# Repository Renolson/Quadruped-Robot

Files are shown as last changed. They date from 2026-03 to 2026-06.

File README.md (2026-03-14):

<h1 align="center">🐾 12-DOF Quadrupedal Robot</h1>

<p align="center">
<b>Development of a 12-DOF Quadrupedal Robot with Enhanced Navigation</b>
</p>

<p align="center">





</p>
------------------------------------------------------------------------

# 🤖 Project Overview

This project presents the **design and development of a
12‑Degree‑of‑Freedom (12‑DOF) quadrupedal robot** capable of navigating
uneven terrain.

Traditional wheeled robots struggle on **rocky surfaces, stairs, and
irregular ground**.\
Legged robots provide superior mobility by adapting their footholds and
posture.

Our robot uses:

-   🧠 **Raspberry Pi embedded control**
-   ⚙️ **High‑torque servo actuators**
-   🦾 **12 articulated joints**
-   🖥 **Inverse kinematics based motion control**
-   🎮 **Remote controller interface**

The goal is to create a **cost‑effective quadruped research platform**
suitable for robotics experimentation and education.

------------------------------------------------------------------------

# 🐕 Robot Preview

<p align="center">
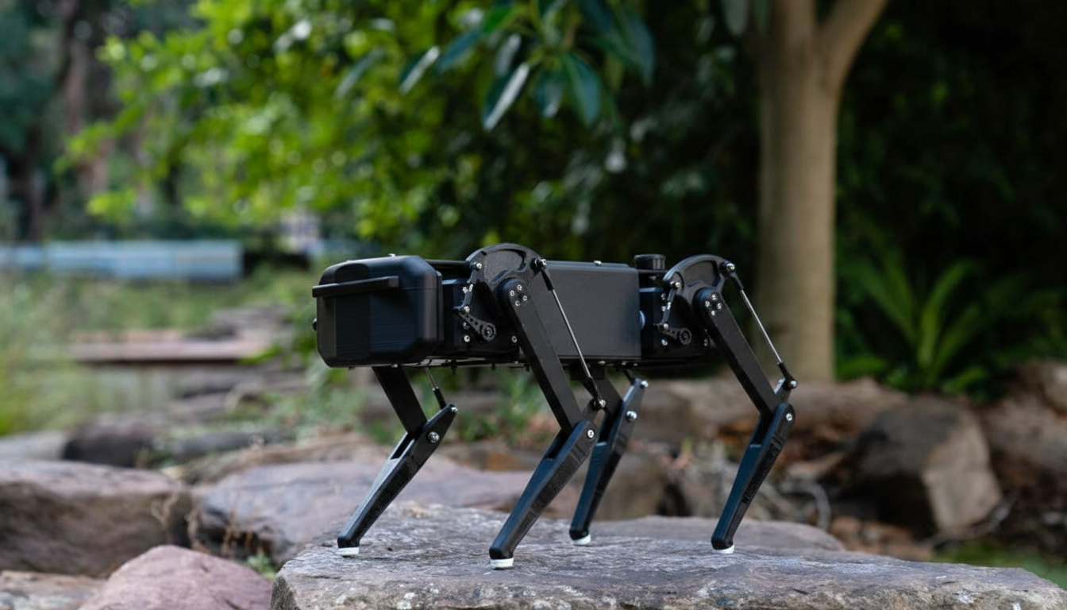
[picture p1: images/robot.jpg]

</p>

> This is a 3D design inspired and altered from the Open Source 3D model- DINGO THE ROBOT DOG.
> Credits Goes to the respective owners

------------------------------------------------------------------------

# ✨ Key Features

  Feature                         Description
  ------------------------------- -----------------------------------------
  🦾 12‑DOF Leg Design            3 joints per leg for natural locomotion
  🧠 Embedded Control             Raspberry Pi based architecture
  ⚙️ Torque‑Validated Actuation   Analytical actuator selection
  🎮 Remote Control               PS4 controller / keyboard input
  🧩 Modular Design               Easy upgrades for future research
  🌍 Terrain Adaptability         Handles uneven surfaces and slopes

------------------------------------------------------------------------

# 🧠 System Architecture

    User Input (PS4 Controller / Keyboard)
                │
                ▼
          Raspberry Pi Controller
                │
          Gait Controller
                │
          Inverse Kinematics
                │
          Hardware Interface
                │
            Servo Driver
                │
            Servo Motors

------------------------------------------------------------------------

# ⚙️ Robot Specifications

  Parameter            Value
  -------------------- ------------------
  Degrees of Freedom   12 DOF
  Leg Configuration    3 joints per leg
  Body Length          380 mm
  Body Width           250 mm
  Shoulder Height      250 mm
  Thigh Length         140 mm
  Shank Length         140 mm
  Robot Mass           \~3 kg
  Payload Capacity     \~0.5 kg

------------------------------------------------------------------------

# 🔧 Hardware Components

## Embedded Controller

-   Raspberry Pi

## Actuators

-   STS3215 Serial Servo
-   35kg PWM Servo

## Mechanical Structure

-   3D printed polycarbonate components

## Communication

-   I2C servo communication
-   PWM servo control

------------------------------------------------------------------------

# 🧮 Torque Validation

Joint torque was analytically calculated to ensure proper actuator
selection.

Example:

τ = m × g × L

For the knee joint:

τ ≈ 2.06 Nm

Selected actuators provide **higher torque than required**, ensuring
stable operation.

------------------------------------------------------------------------

# 🧪 Testing

The robot was tested through several stages:

### Static Testing

-   Posture validation
-   Load‑bearing verification
-   Joint limit testing

### Dynamic Testing

-   Forward walking
-   Turning
-   Incline traversal

### Monitoring

-   Servo temperature
-   Power consumption

The robot successfully demonstrated **stable walking and controlled
locomotion**.

------------------------------------------------------------------------

# 🌍 Applications

Quadrupedal robots can be used in:

-   🚨 Disaster inspection
-   🧭 Rough terrain exploration
-   🌾 Agricultural monitoring
-   🏭 Industrial inspection
-   🔍 Search and rescue missions

------------------------------------------------------------------------

# 🔮 Future Work

Future improvements may include:

-   Computer vision navigation
-   SLAM based localization
-   IMU stabilization
-   Autonomous path planning
-   Advanced gait optimization

------------------------------------------------------------------------

# 📂 Repository Structure

    quadruped-robot
    │
    ├── CAD
    │   ├── body_design
    │   └── leg_components
    │
    ├── firmware
    │   └── servo_control
    │
    ├── control
    │   ├── gait_controller
    │   └── inverse_kinematics
    │
    ├── simulation
    │   └── gazebo
    │
    ├── electronics
    │   └── wiring_diagrams
    │
    ├── images
    │   ├── robot.jpg
    │   └── demo.gif
    │
    └── README.md

------------------------------------------------------------------------

# 🎓 Academic Information

**BSc Engineering (Hons)**\
Department of Electrical and Telecommunication Engineering\
South Eastern University of Sri Lanka

### Authors

Balakumar Premamyuresan\
Sahayanathan Renolson\
Jeyapalasingam Jeluxshan

### Supervisors

Dr. W.G.C.W Kumara\
Dr. Ajmal Hinas\
Eng. S. Sampavi

------------------------------------------------------------------------

# ⭐ Contribution

This project demonstrates that **locally engineered quadrupedal robots** can be developed using accessible hardware, supporting robotics research and education.

---

# 📜 License

Academic research project.

---

<p align="center">
⭐ If you like this project, consider giving it a star!
</p>

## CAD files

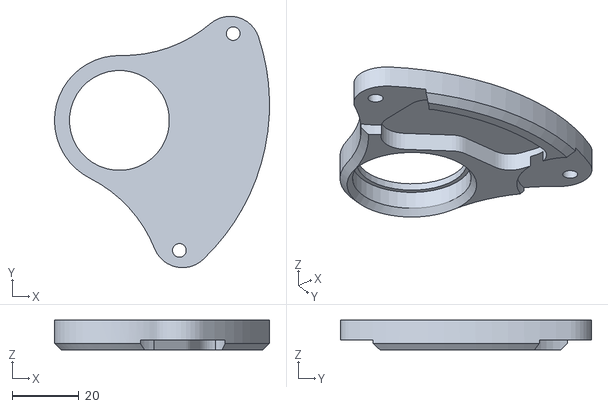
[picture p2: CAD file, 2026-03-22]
Printed parts outside/left leg front STL/leg left - Servo CAM offset modd-1.STL
64.6 x 75.5 x 9.00

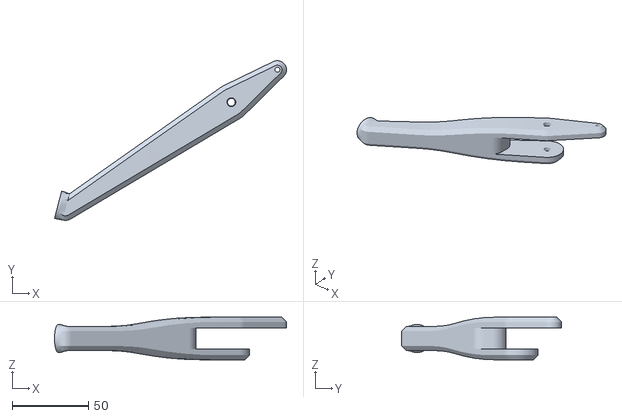
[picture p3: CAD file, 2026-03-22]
Printed parts outside/left leg front STL/leg left - RIGHT Lower Leg simpleMirror-2.STL
152.5 x 105.0 x 28.0

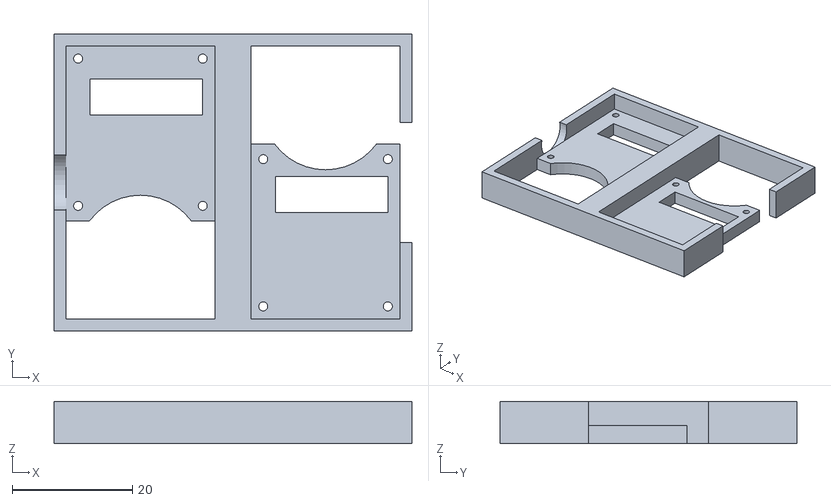
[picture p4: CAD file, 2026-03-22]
Printed parts outside/left leg front STL/12servo - cover12servo-1.STL
59.6 x 49.4 x 7.00

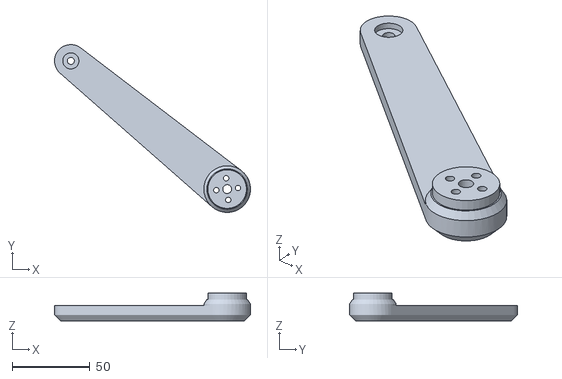
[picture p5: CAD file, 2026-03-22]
Printed parts outside/left leg front STL/leg left - RIGHT upper leggg-1.STL
126.0 x 107.9 x 18.0

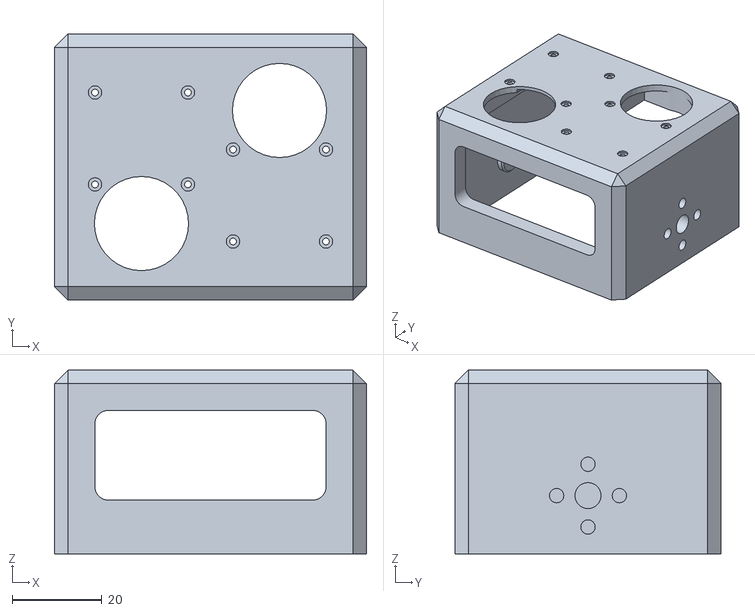
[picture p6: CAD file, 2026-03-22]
Printed parts outside/left leg front STL/12servo - holder3-1.STL
69.6 x 59.4 x 41.0

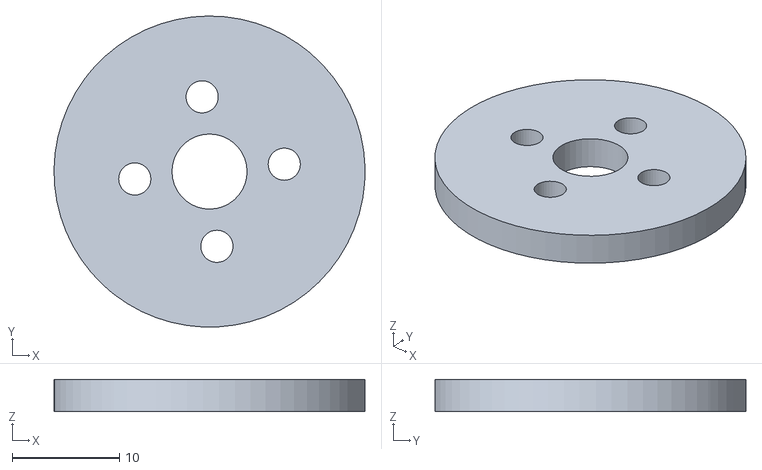
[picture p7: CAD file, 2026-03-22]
Printed parts outside/left leg front STL/leg left - Upper leg bearing washerr-1.STL
29.0 x 29.0 x 3.00

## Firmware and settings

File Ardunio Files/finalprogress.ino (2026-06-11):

#include <INST.h>
#include <SCS.h>
#include <SCSCL.h>
#include <SCSerial.h>
#include <SCServo.h>
#include <SMS_STS.h>
#include <Arduino.h>
#include <math.h>

// =====================================================
// ESP32 + FE-URT-1 + 12 x STS3215
// Complete Robot Dog Demo Code (Walking + Gestures)
// CH1: Forward / Backward Trot
// CH5: Push-up / Back push-up
// CH6 HIGH: Hip sway
// CH6 LOW: Sitting + Heart / Hi gestures
// =====================================================

// ---------------- UART SETTINGS ----------------
#define SERVO_RX 16
#define SERVO_TX 17
#define SERVO_BAUD 1000000

HardwareSerial ServoSerial(1);
SMS_STS sts;

// ---------------- RC RECEIVER ----------------
#define CH1_PIN 32
#define CH5_PIN 27
#define CH6_PIN 14

// ---------------- MOTOR SETTINGS ----------------
const int NUM_MOTORS = 12;

int motorID[NUM_MOTORS] = {
  1, 2, 3,
  4, 5, 6,
  7, 8, 9,
  10, 11, 12
};

// =====================================================
// REAL MOTOR MAPPING
// =====================================================

// Front Right
#define FR_LOWER 1
#define FR_UPPER 2
#define FR_HIP   3

// Front Left
#define FL_HIP   10
#define FL_UPPER 11
#define FL_LOWER 12

// Back Left
#define BL_HIP   4
#define BL_UPPER 6
#define BL_LOWER 5

// Back Right
#define BR_HIP   9
#define BR_UPPER 7
#define BR_LOWER 8

// =====================================================
// FIXED HOME POSITION
// =====================================================

int fixedHomePos[NUM_MOTORS] = {
  2000, 2110, 2045,
  2000, 1885, 2120,
  2048, 2075, 2100,
  2100, 2048, 2048
};

int homePos[NUM_MOTORS];
int currentCmdPos[NUM_MOTORS];

// =====================================================
// SITTING POSES
// =====================================================

// Go here first when sitting
int intermediateSitPose[NUM_MOTORS] = {
  2549, 2596, 2076,
  2019, 2513, 2557,
  1526, 1442, 2048,
  2118, 1597, 1516
};

// Final sitting pose
int sittingPose[NUM_MOTORS] = {
  2349, 2567, 2098,
  1985, 1944, 2738,
  1326, 1978, 2095,
  2060, 1309, 1679
};

// Use this when returning from sitting
int intermediateReturnPose[NUM_MOTORS] = {
  1838, 2604, 2128,
  1955, 2195, 2961,
  1115, 1741, 2081,
  2105, 1645, 2216
};

// =====================================================
// SERVO & MOVEMENT SETTINGS
// =====================================================

int moveSpeed = 550;
int moveAcc   = 45;

int moveSteps = 30;
int moveDelay = 20;

int pushOffset = 600;
int supportOffset = 220;
int swayOffset = 220;
int maxOffsetLimit = 420;

// Right/left correction for upper leg pair movement
int rightSign = 1;
int leftSign  = -1;

// =====================================================
// DINGO-BASED TRAJECTORY TUNING PARAMETERS (IK)
// =====================================================
const float LINK_UPPER_MM = 40.0;
const float LINK_LOWER_MM = 40.0;
const float HOME_FOOT_X_MM = -20.0;
const float HOME_FOOT_Z_MM = -60.0;
const float STEP_LENGTH_MM = 15.0; 
const float STEP_HEIGHT_MM = 8.0; 
const float CYCLE_TIME_MS  = 2000.0; 
const int   GAIT_DT_MS     = 25;     
const float SERVO_COUNT_PER_DEG = 4096.0 / 360.0;

int SIGN_FR_UPPER =  1;
int SIGN_FR_LOWER =  1;
int SIGN_FL_UPPER = -1;
int SIGN_FL_LOWER = -1;
int SIGN_BR_UPPER =  1;
int SIGN_BR_LOWER =  1;
int SIGN_BL_UPPER = -1;
int SIGN_BL_LOWER = -1;

unsigned long lastPrintMs = 0;

struct IK_Result {
  int upperCount;
  int lowerCount;
  bool valid;
};

// =====================================================
// HELPER FUNCTIONS
// =====================================================

int idToIndex(int id) {
  return id - 1;
}

int limitPosition(int pos) {
  if (pos < 0) return 0;
  if (pos > 4095) return 4095;
  return pos;
}

int limitOffset(int offset) {
  if (offset > maxOffsetLimit) return maxOffsetLimit;
  if (offset < -maxOffsetLimit) return -maxOffsetLimit;
  return offset;
}

void writeMotorPosition(int id, int targetPos) {
  targetPos = limitPosition(targetPos);
  sts.WritePosEx(id, targetPos, moveSpeed, moveAcc);
}

int readChannelRaw(int pin) {
  return pulseIn(pin, HIGH, 25000);
}

int readChannel(int pin) {
  int value = readChannelRaw(pin);
  if (value < 900 || value > 2100) {
    return 1500;
  }
  return value;
}

void copyPose(int sourcePose[NUM_MOTORS], int targetPose[NUM_MOTORS]) {
  for (int i = 0; i < NUM_MOTORS; i++) {
    targetPose[i] = sourcePose[i];
  }
}

// =====================================================
// HOME FUNCTIONS
// =====================================================

void loadFixedHomePositions() {
  Serial.println("Loading fixed HOME positions...");
  for (int i = 0; i < NUM_MOTORS; i++) {
    homePos[i] = fixedHomePos[i];
  }
}

void readCurrentPositions() {
  Serial.println("Reading current motor positions...");
  for (int i = 0; i < NUM_MOTORS; i++) {
    int id = motorID[i];
    int pos = sts.ReadPos(id);

    if (pos < 0 || pos > 4095) {
      pos = homePos[i];
    }
    currentCmdPos[i] = pos;
    delay(15);
  }
}

void moveToHome() {
  int startPose[NUM_MOTORS];
  for (int i = 0; i < NUM_MOTORS; i++) {
    startPose[i] = currentCmdPos[i];
  }

  for (int step = 1; step <= moveSteps; step++) {
    float t = (float)step / (float)moveSteps;

    for (int i = 0; i < NUM_MOTORS; i++) {
      int newPos = startPose[i] + (homePos[i] - startPose[i]) * t;
      newPos = limitPosition(newPos);
      writeMotorPosition(motorID[i], newPos);
      currentCmdPos[i] = newPos;
    }
    delay(moveDelay);
  }

  for (int i = 0; i < NUM_MOTORS; i++) {
    currentCmdPos[i] = homePos[i];
  }
}

// =====================================================
// INVERSE KINEMATICS & TRAJECTORY (TROT)
// =====================================================

IK_Result calculateIK(float x, float z, int homeUpper, int homeLower, int signUpper, int signLower) {
  IK_Result res;
  res.valid = false;

  float d_sq = x*x + z*z;
  float d = sqrt(d_sq);

  if (d > (LINK_UPPER_MM + LINK_LOWER_MM) || d < fabs(LINK_UPPER_MM - LINK_LOWER_MM)) {
    return res; 
  }

  float cos_lower = (d_sq - LINK_UPPER_MM*LINK_UPPER_MM - LINK_LOWER_MM*LINK_LOWER_MM) / (2.0 * LINK_UPPER_MM * LINK_LOWER_MM);
  float alpha_lower = acos(cos_lower); 

  float alpha_1 = atan2(x, -z);
  float cos_alpha2 = (LINK_UPPER_MM*LINK_UPPER_MM + d_sq - LINK_LOWER_MM*LINK_LOWER_MM) / (2.0 * LINK_UPPER_MM * d);
  float alpha_2 = acos(cos_alpha2);
  float alpha_upper = alpha_1 + alpha_2; 

  float d_sq_home = HOME_FOOT_X_MM*HOME_FOOT_X_MM + HOME_FOOT_Z_MM*HOME_FOOT_Z_MM;
  float d_home = sqrt(d_sq_home);
  float cos_lower_home = (d_sq_home - LINK_UPPER_MM*LINK_UPPER_MM - LINK_LOWER_MM*LINK_LOWER_MM) / (2.0 * LINK_UPPER_MM * LINK_LOWER_MM);
  float alpha_lower_home = acos(cos_lower_home);
  float alpha_1_home = atan2(HOME_FOOT_X_MM, -HOME_FOOT_Z_MM);
  float cos_alpha2_home = (LINK_UPPER_MM*LINK_UPPER_MM + d_sq_home - LINK_LOWER_MM*LINK_LOWER_MM) / (2.0 * LINK_UPPER_MM * d_home);
  float alpha_2_home = acos(cos_alpha2_home);
  float alpha_upper_home = alpha_1_home + alpha_2_home;

  float delta_upper_deg = (alpha_upper - alpha_upper_home) * 180.0 / M_PI;
  float delta_lower_deg = (alpha_lower - alpha_lower_home) * 180.0 / M_PI;

  int upperOffsetTicks = round(delta_upper_deg * SERVO_COUNT_PER_DEG);
  int lowerOffsetTicks = round(delta_lower_deg * SERVO_COUNT_PER_DEG);

  res.upperCount = limitPosition(homeUpper + (signUpper * upperOffsetTicks));
  res.lowerCount = limitPosition(homeLower + (signLower * lowerOffsetTicks));
  res.valid = true;
  return res;
}

void getTrajectoryPoint(float phase, float &x, float &z) {
  float halfLength = STEP_LENGTH_MM / 2.0;

  if (phase < 0.5) {
    float t_swing = phase / 0.5; 
    float x_start = halfLength; 
    float x_end   = -halfLength;
    
    x = HOME_FOOT_X_MM + x_start + (x_end - x_start) * t_swing;
    z = HOME_FOOT_Z_MM + STEP_HEIGHT_MM * sin(t_swing * M_PI);
  } else {
    float t_stance = (phase - 0.5) / 0.5;
    float x_start = -halfLength;
    float x_end   = halfLength;
    
    x = HOME_FOOT_X_MM + x_start + (x_end - x_start) * t_stance;
    z = HOME_FOOT_Z_MM;
  }
}

void executeTrajectoryTrot(int walkDirection) {
  unsigned long strideStartMs = millis();
  
  while (true) {
    int ch1 = readChannel(CH1_PIN);
    int ch5 = readChannel(CH5_PIN);
    int ch6 = readChannel(CH6_PIN);
    
    if (walkDirection > 0 && ch1 < 1700) break;
    if (walkDirection < 0 && ch1 > 1300) break;
    if (ch5 > 1700 || ch5 < 1300 || ch6 > 1700 || ch6 < 1300) break;

    unsigned long elapsedMs = millis() - strideStartMs;
    float basePhase = fmod((float)elapsedMs / CYCLE_TIME_MS, 1.0);

    float phase_FR_BL;
    float phase_FL_BR;

    if (walkDirection < 0) {
      phase_FR_BL = basePhase;
      phase_FL_BR = fmod(basePhase + 0.5, 1.0);
    } else {
      phase_FR_BL = fmod(1.0 - basePhase, 1.0);
      phase_FL_BR = fmod(phase_FR_BL + 0.5, 1.0);
    }

    float x_FR_BL, z_FR_BL;
    float x_FL_BR, z_FL_BR;

    getTrajectoryPoint(phase_FR_BL, x_FR_BL, z_FR_BL);
    getTrajectoryPoint(phase_FL_BR, x_FL_BR, z_FL_BR);

    IK_Result fr = calculateIK(x_FR_BL, z_FR_BL, homePos[idToIndex(FR_UPPER)], homePos[idToIndex(FR_LOWER)], SIGN_FR_UPPER, SIGN_FR_LOWER);
    IK_Result bl = calculateIK(x_FR_BL, z_FR_BL, homePos[idToIndex(BL_UPPER)], homePos[idToIndex(BL_LOWER)], SIGN_BL_UPPER, SIGN_BL_LOWER);
    IK_Result fl = calculateIK(x_FL_BR, z_FL_BR, homePos[idToIndex(FL_UPPER)], homePos[idToIndex(FL_LOWER)], SIGN_FL_UPPER, SIGN_FL_LOWER);
    IK_Result br = calculateIK(x_FL_BR, z_FL_BR, homePos[idToIndex(BR_UPPER)], homePos[idToIndex(BR_LOWER)], SIGN_BR_UPPER, SIGN_BR_LOWER);

    if (fr.valid && bl.valid && fl.valid && br.valid) {
      writeMotorPosition(FR_UPPER, fr.upperCount);
      writeMotorPosition(FR_LOWER, fr.lowerCount);
      writeMotorPosition(BL_UPPER, bl.upperCount);
      writeMotorPosition(BL_LOWER, bl.lowerCount);

      writeMotorPosition(FL_UPPER, fl.upperCount);
      writeMotorPosition(FL_LOWER, fl.lowerCount);
      writeMotorPosition(BR_UPPER, br.upperCount);
      writeMotorPosition(BR_LOWER, br.lowerCount);

      currentCmdPos[idToIndex(FR_UPPER)] = fr.upperCount;
      currentCmdPos[idToIndex(FR_LOWER)] = fr.lowerCount;
      currentCmdPos[idToIndex(BL_UPPER)] = bl.upperCount;
      currentCmdPos[idToIndex(BL_LOWER)] = bl.lowerCount;
      currentCmdPos[idToIndex(FL_UPPER)] = fl.upperCount;
      currentCmdPos[idToIndex(FL_LOWER)] = fl.lowerCount;
      currentCmdPos[idToIndex(BR_UPPER)] = br.upperCount;
      currentCmdPos[idToIndex(BR_LOWER)] = br.lowerCount;
    }

    delay(GAIT_DT_MS);
  }
  
  moveToHome();
}

// =====================================================
// CUSTOM POSE MOVEMENT
// =====================================================

void moveToCustomPoseSmooth(int targetPose[NUM_MOTORS], int steps, int stepDelay) {
  int startPose[NUM_MOTORS];
  for (int i = 0; i < NUM_MOTORS; i++) {
    startPose[i] = currentCmdPos[i];
  }

  for (int step = 1; step <= steps; step++) {
    float t = (float)step / (float)steps;
    for (int i = 0; i < NUM_MOTORS; i++) {
      int newPos = startPose[i] + (targetPose[i] - startPose[i]) * t;
      newPos = limitPosition(newPos);
      writeMotorPosition(motorID[i], newPos);
      currentCmdPos[i] = newPos;
    }
    delay(stepDelay);
  }
  
  for (int i = 0; i < NUM_MOTORS; i++) {
    currentCmdPos[i] = targetPose[i];
  }
}

void holdPose(int targetPose[NUM_MOTORS]) {
  for (int i = 0; i < NUM_MOTORS; i++) {
    writeMotorPosition(motorID[i], targetPose[i]);
    currentCmdPos[i] = targetPose[i];
  }
}

// =====================================================
// RECOVERY SEQUENCES 
// =====================================================

void moveSelectedMotorsToHome(int selectedMotors[], int count, int steps, int stepDelay) {
  int startPos[12];
  int targetPos[12];

  for (int i = 0; i < count; i++) {
    int id = selectedMotors[i];
    int index = idToIndex(id);
    startPos[i] = currentCmdPos[index];
    targetPos[i] = homePos[index];
  }

  for (int step = 1; step <= steps; step++) {
    float t = (float)step / (float)steps;
    for (int i = 0; i < count; i++) {
      int id = selectedMotors[i];
      int index = idToIndex(id);
      int newPos = startPos[i] + (targetPos[i] - startPos[i]) * t;
      newPos = limitPosition(newPos);
      writeMotorPosition(id, newPos);
      currentCmdPos[index] = newPos;
    }
    delay(stepDelay);
  }

  for (int i = 0; i < count; i++) {
    int index = idToIndex(selectedMotors[i]);
    currentCmdPos[index] = homePos[index];
  }
}

void moveBack5678ToRecoveryPose(int m5Target, int m6Target, int m7Target, int m8Target, int steps, int stepDelay) {
  int ids[4] = {5, 6, 7, 8};
  int targets[4] = {m5Target, m6Target, m7Target, m8Target};
  int starts[4];

  for (int i = 0; i < 4; i++) {
    int index = idToIndex(ids[i]);
    starts[i] = currentCmdPos[index];
    targets[i] = limitPosition(targets[i]);
  }

  for (int step = 1; step <= steps; step++) {
    float t = (float)step / (float)steps;
    for (int i = 0; i < 4; i++) {
      int id = ids[i];
      int index = idToIndex(id);
      int newPos = starts[i] + (targets[i] - starts[i]) * t;
      newPos = limitPosition(newPos);
      writeMotorPosition(id, newPos);
      currentCmdPos[index] = newPos;
    }
    delay(stepDelay);
  }

  for (int i = 0; i < 4; i++) {
    currentCmdPos[idToIndex(ids[i])] = targets[i];
  }
}

void back5678RecoverySequence() {
  moveBack5678ToRecoveryPose(2140, 2931, 1122, 1780, 28, 16);
  moveBack5678ToRecoveryPose(2290, 2733, 1322, 1630, 28, 16);
  moveBack5678ToRecoveryPose(2370, 2520, 1535, 1550, 28, 16);
  moveBack5678ToRecoveryPose(2290, 2420, 1635, 1630, 28, 16);
  moveBack5678ToRecoveryPose(2160, 2320, 1735, 1684, 28, 16);
}

// =====================================================
// UPPER LEG & PUSH-UP FUNCTIONS
// =====================================================

int getRightUpperTarget(int rightMotor, int offset) {
  int idx = idToIndex(rightMotor);
  return limitPosition(homePos[idx] + rightSign * limitOffset(offset));
}

int getLeftUpperTarget(int leftMotor, int offset) {
  int idx = idToIndex(leftMotor);
  return limitPosition(homePos[idx] + leftSign * limitOffset(offset));
}

void moveUpperPairFromHome(int rightUpperMotor, int leftUpperMotor, int offset) {
  offset = limitOffset(offset);
  int rightIndex = idToIndex(rightUpperMotor);
  int leftIndex  = idToIndex(leftUpperMotor);

  int rightTarget = getRightUpperTarget(rightUpperMotor, offset);
  int leftTarget  = getLeftUpperTarget(leftUpperMotor, offset);

  int rightStart = currentCmdPos[rightIndex];
  int leftStart  = currentCmdPos[leftIndex];

  for (int step = 1; step <= moveSteps; step++) {
    float t = (float)step / (float)moveSteps;
    int rightNew = limitPosition(rightStart + (rightTarget - rightStart) * t);
    int leftNew  = limitPosition(leftStart  + (leftTarget  - leftStart)  * t);

    writeMotorPosition(rightUpperMotor, rightNew);
    writeMotorPosition(leftUpperMotor, leftNew);

    currentCmdPos[rightIndex] = rightNew;
    currentCmdPos[leftIndex]  = leftNew;
    delay(moveDelay);
  }
}

void moveActivePairWithSupport(int activeRight, int activeLeft, int activeOffset, int supportRight, int supportLeft, int supportFixedOffset) {
  int activeRightIndex = idToIndex(activeRight);
  int activeLeftIndex  = idToIndex(activeLeft);
  int supportRightIndex = idToIndex(supportRight);
  int supportLeftIndex  = idToIndex(supportLeft);

  int activeRightTarget = getRightUpperTarget(activeRight, activeOffset);
  int activeLeftTarget  = getLeftUpperTarget(activeLeft, activeOffset);
  int supportRightTarget = getRightUpperTarget(supportRight, supportFixedOffset);
  int supportLeftTarget  = getLeftUpperTarget(supportLeft, supportFixedOffset);

  int activeRightStart = currentCmdPos[activeRightIndex];
  int activeLeftStart  = currentCmdPos[activeLeftIndex];

  for (int step = 1; step <= moveSteps; step++) {
    float t = (float)step / (float)moveSteps;
    int activeRightNew = limitPosition(activeRightStart + (activeRightTarget - activeRightStart) * t);
    int activeLeftNew  = limitPosition(activeLeftStart  + (activeLeftTarget  - activeLeftStart)  * t);

    writeMotorPosition(activeRight, activeRightNew);
    writeMotorPosition(activeLeft, activeLeftNew);
    writeMotorPosition(supportRight, supportRightTarget);
    writeMotorPosition(supportLeft, supportLeftTarget);

    currentCmdPos[activeRightIndex] = activeRightNew;
    currentCmdPos[activeLeftIndex]  = activeLeftNew;
    currentCmdPos[supportRightIndex] = supportRightTarget;
    currentCmdPos[supportLeftIndex]  = supportLeftTarget;
    delay(moveDelay);
  }
}

void frontPushUpCycle() {
  int backLowerOffset = supportOffset;
  moveUpperPairFromHome(BR_UPPER, BL_UPPER, backLowerOffset);

  while (readChannel(CH5_PIN) > 1700) {
    moveActivePairWithSupport(FR_UPPER, FL_UPPER, pushOffset, BR_UPPER, BL_UPPER, backLowerOffset);
    moveActivePairWithSupport(FR_UPPER, FL_UPPER, -pushOffset, BR_UPPER, BL_UPPER, backLowerOffset);
  }
  moveToHome();
}

void backPushUpCycle() {
  int frontLowerOffset = -supportOffset;
  moveUpperPairFromHome(FR_UPPER, FL_UPPER, frontLowerOffset);

  while (readChannel(CH5_PIN) < 1300) {
    moveActivePairWithSupport(BR_UPPER, BL_UPPER, pushOffset, FR_UPPER, FL_UPPER, frontLowerOffset);
    moveActivePairWithSupport(BR_UPPER, BL_UPPER, -pushOffset, FR_UPPER, FL_UPPER, frontLowerOffset);
  }
  moveToHome();
}

// =====================================================
// HIP SWAY FUNCTION
// =====================================================

void moveFourHipsFromHome(int motorA, int offsetA, int motorB, int offsetB, int motorC, int offsetC, int motorD, int offsetD) {
  offsetA = limitOffset(offsetA); offsetB = limitOffset(offsetB);
  offsetC = limitOffset(offsetC); offsetD = limitOffset(offsetD);

  int indexA = idToIndex(motorA); int indexB = idToIndex(motorB);
  int indexC = idToIndex(motorC); int indexD = idToIndex(motorD);

  int startA = currentCmdPos[indexA]; int startB = currentCmdPos[indexB];
  int startC = currentCmdPos[indexC]; int startD = currentCmdPos[indexD];

  int targetA = limitPosition(homePos[indexA] + offsetA);
  int targetB = limitPosition(homePos[indexB] + offsetB);
  int targetC = limitPosition(homePos[indexC] + offsetC);
  int targetD = limitPosition(homePos[indexD] + offsetD);

  for (int step = 1; step <= moveSteps; step++) {
    float t = (float)step / (float)moveSteps;

    int newA = limitPosition(startA + (targetA - startA) * t);
    int newB = limitPosition(startB + (targetB - startB) * t);
    int newC = limitPosition(startC + (targetC - startC) * t);
    int newD = limitPosition(startD + (targetD - startD) * t);

    writeMotorPosition(motorA, newA); writeMotorPosition(motorB, newB);
    writeMotorPosition(motorC, newC); writeMotorPosition(motorD, newD);

    currentCmdPos[indexA] = newA; currentCmdPos[indexB] = newB;
    currentCmdPos[indexC] = newC; currentCmdPos[indexD] = newD;
    delay(moveDelay);
  }
}

void hipSwayCycle() {
  while (readChannel(CH6_PIN) > 1700) {
    moveFourHipsFromHome(FR_HIP, swayOffset, BL_HIP, -swayOffset, FL_HIP, swayOffset, BR_HIP, -swayOffset);
    delay(300);
    moveToHome();
    delay(200);

    if (readChannel(CH6_PIN) <= 1700) break;

    moveFourHipsFromHome(FR_HIP, -swayOffset, BL_HIP, swayOffset, FL_HIP, -swayOffset, BR_HIP, swayOffset);
    delay(300);
    moveToHome();
    delay(200);
  }
  moveToHome();
}

// =====================================================
// SITTING GESTURES
// =====================================================

void sittingHeartGesture() {
  int heartOpen[NUM_MOTORS];
  int heartClose[NUM_MOTORS];

  copyPose(sittingPose, heartOpen);
  copyPose(sittingPose, heartClose);

  heartOpen[idToIndex(FR_HIP)]   = sittingPose[idToIndex(FR_HIP)] + 120;
  heartOpen[idToIndex(FR_UPPER)] = sittingPose[idToIndex(FR_UPPER)] - 180;
  heartOpen[idToIndex(FR_LOWER)] = sittingPose[idToIndex(FR_LOWER)] + 120;

  heartOpen[idToIndex(FL_HIP)]   = sittingPose[idToIndex(FL_HIP)] - 120;
  heartOpen[idToIndex(FL_UPPER)] = sittingPose[idToIndex(FL_UPPER)] + 180;
  heartOpen[idToIndex(FL_LOWER)] = sittingPose[idToIndex(FL_LOWER)] - 120;

  heartClose[idToIndex(FR_HIP)]   = sittingPose[idToIndex(FR_HIP)] - 120;
  heartClose[idToIndex(FR_UPPER)] = sittingPose[idToIndex(FR_UPPER)] - 260;
  heartClose[idToIndex(FR_LOWER)] = sittingPose[idToIndex(FR_LOWER)] + 220;

  heartClose[idToIndex(FL_HIP)]   = sittingPose[idToIndex(FL_HIP)] + 120;
  heartClose[idToIndex(FL_UPPER)] = sittingPose[idToIndex(FL_UPPER)] + 260;
  heartClose[idToIndex(FL_LOWER)] = sittingPose[idToIndex(FL_LOWER)] - 220;

  moveToCustomPoseSmooth(heartOpen, 25, 12);
  delay(150);
  moveToCustomPoseSmooth(heartClose, 25, 12);
  delay(300);
  moveToCustomPoseSmooth(sittingPose, 25, 12);
}
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
void loop() {
  int ch1Raw = readChannelRaw(CH1_PIN);
  int ch5Raw = readChannelRaw(CH5_PIN);
  int ch6Raw = readChannelRaw(CH6_PIN);
  
  int ch1 = (ch1Raw >= 900 && ch1Raw <= 2100) ? ch1Raw : 1500;
  int ch5 = (ch5Raw >= 900 && ch5Raw <= 2100) ? ch5Raw : 1500;
  int ch6 = (ch6Raw >= 900 && ch6Raw <= 2100) ? ch6Raw : 1500;

  if (millis() - lastPrintMs > 350) {
    lastPrintMs = millis();
    Serial.print("CH1="); Serial.print(ch1);
    Serial.print("  CH5="); Serial.print(ch5);
    Serial.print("  CH6="); Serial.println(ch6);
  }

  // Hierarchy of movement commands
  if (ch1 > 1700) {
    executeTrajectoryTrot(1); 
  }
  else if (ch1 < 1300) {
    executeTrajectoryTrot(-1); 
  }
  else if (ch6 > 1700) {
    hipSwayCycle();
  }
  else if (ch6 < 1300) {
    hipSitSmooth();
  }
  else if (ch5 > 1700) {
    frontPushUpCycle();
  }
  else if (ch5 < 1300) {
    backPushUpCycle();
  }
  else {
    // Small delay to prevent tight-looping while reading pulseIn
    delay(20);
  }
}

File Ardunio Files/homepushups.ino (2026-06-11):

#include <Arduino.h>
#include <SMS_STS.h>

// =====================================================
// ESP32 + FE-URT-1 + 12 x STS3215
// CH5 Push-up Demo
// Initial HOME pose at power ON
// Front push-up: back side lowers and stays lowered
// Back push-up : front side lowers and stays lowered
// =====================================================

// ---------------- UART SETTINGS ----------------
#define SERVO_RX 16
#define SERVO_TX 17
#define SERVO_BAUD 1000000

HardwareSerial ServoSerial(1);
SMS_STS sts;

// ---------------- RC RECEIVER ----------------
#define CH5_PIN 27

// ---------------- MOTOR SETTINGS ----------------
const int NUM_MOTORS = 12;

int motorID[NUM_MOTORS] = {
  1, 2, 3,
  4, 5, 6,
  7, 8, 9,
  10, 11, 12
};

// =====================================================
// REAL MOTOR MAPPING
// =====================================================

// Front Right
#define FR_LOWER 1
#define FR_UPPER 2
#define FR_HIP   3

// Front Left
#define FL_HIP   10
#define FL_UPPER 11
#define FL_LOWER 12

// Back Left
#define BL_HIP   4
#define BL_UPPER 6
#define BL_LOWER 5

// Back Right
#define BR_HIP   9
#define BR_UPPER 7
#define BR_LOWER 8

// =====================================================
// FIXED HOME POSITION
// =====================================================
// Your current HOME pose values

int fixedHomePos[NUM_MOTORS] = {
  2000, 2110, 2045,
  2000, 1885, 2120,
  2048, 2075, 2100,
  2100, 2048, 2048
};

int homePos[NUM_MOTORS];
int currentCmdPos[NUM_MOTORS];

// ---------------- SERVO SETTINGS ----------------
int moveSpeed = 550;
int moveAcc   = 45;

// Movement smoothness
int moveSteps = 30;
int moveDelay = 20;

// Main push-up movement size
int pushOffset = 600;

// Opposite side lowering amount
// If support side is still going high, change sign of support offset below.
int supportOffset = 220;

// Safety limit
int maxOffsetLimit = 420;

// =====================================================
// RIGHT / LEFT DIRECTION
// =====================================================
// Your right and left motors are mounted opposite.

int rightSign = 1;
int leftSign  = -1;

// =====================================================
// HELPER FUNCTIONS
// =====================================================

int idToIndex(int id) {
  return id - 1;
}

int limitPosition(int pos) {
  if (pos < 0) return 0;
  if (pos > 4095) return 4095;
  return pos;
}

int limitOffset(int offset) {
  if (offset > maxOffsetLimit) return maxOffsetLimit;
  if (offset < -maxOffsetLimit) return -maxOffsetLimit;
  return offset;
}

void writeMotorPosition(int id, int targetPos) {
  targetPos = limitPosition(targetPos);
  sts.WritePosEx(id, targetPos, moveSpeed, moveAcc);
}

int readChannel(int pin) {
  int value = pulseIn(pin, HIGH, 25000);

  // If receiver signal missing, return HOME zone
  if (value < 900 || value > 2100) {
    return 1500;
  }

  return value;
}

// =====================================================
// HOME FUNCTIONS
// =====================================================

void loadFixedHomePositions() {
  Serial.println("Loading fixed HOME positions...");

  for (int i = 0; i < NUM_MOTORS; i++) {
    homePos[i] = fixedHomePos[i];

    Serial.print("Motor ");
    Serial.print(i + 1);
    Serial.print(" HOME = ");
    Serial.println(homePos[i]);
  }
}

void readCurrentPositions() {
  Serial.println("Reading current motor positions...");

  for (int i = 0; i < NUM_MOTORS; i++) {
    int id = motorID[i];
    int pos = sts.ReadPos(id);

    if (pos < 0 || pos > 4095) {
      Serial.print("WARNING: Could not read motor ");
      Serial.print(id);
      Serial.println(". Using HOME as current.");
      pos = homePos[i];
    }

    currentCmdPos[i] = pos;

    Serial.print("Motor ");
    Serial.print(id);
    Serial.print(" CURRENT = ");
    Serial.println(pos);

    delay(30);
  }
}

void moveToHome() {
  Serial.println("Moving to HOME...");

  for (int step = 1; step <= moveSteps; step++) {
    float t = (float)step / (float)moveSteps;

    for (int i = 0; i < NUM_MOTORS; i++) {
      int startPos = currentCmdPos[i];
      int targetPos = homePos[i];

      int newPos = startPos + (targetPos - startPos) * t;
      newPos = limitPosition(newPos);

      writeMotorPosition(i + 1, newPos);
      delay(2);
    }

    delay(moveDelay);
  }

  for (int i = 0; i < NUM_MOTORS; i++) {
    currentCmdPos[i] = homePos[i];
  }

  Serial.println("HOME reached.");
}

// =====================================================
// TARGET CALCULATION FOR RIGHT / LEFT UPPER PAIR
// =====================================================

int getRightUpperTarget(int rightMotor, int offset) {
  int index = idToIndex(rightMotor);
  offset = limitOffset(offset);
  return limitPosition(homePos[index] + rightSign * offset);
}

int getLeftUpperTarget(int leftMotor, int offset) {
  int index = idToIndex(leftMotor);
  offset = limitOffset(offset);
  return limitPosition(homePos[index] + leftSign * offset);
}

// =====================================================
// MOVE UPPER PAIR FROM HOME
// =====================================================

void moveUpperPairFromHome(int rightUpperMotor, int leftUpperMotor, int offset) {
  offset = limitOffset(offset);

  int rightIndex = idToIndex(rightUpperMotor);
  int leftIndex  = idToIndex(leftUpperMotor);

  int rightTarget = getRightUpperTarget(rightUpperMotor, offset);
  int leftTarget  = getLeftUpperTarget(leftUpperMotor, offset);

  int rightStart = currentCmdPos[rightIndex];
  int leftStart  = currentCmdPos[leftIndex];

  for (int step = 1; step <= moveSteps; step++) {
    float t = (float)step / (float)moveSteps;

    int rightNew = rightStart + (rightTarget - rightStart) * t;
    int leftNew  = leftStart  + (leftTarget  - leftStart)  * t;

    rightNew = limitPosition(rightNew);
    leftNew  = limitPosition(leftNew);

    writeMotorPosition(rightUpperMotor, rightNew);
    writeMotorPosition(leftUpperMotor, leftNew);

    currentCmdPos[rightIndex] = rightNew;
    currentCmdPos[leftIndex]  = leftNew;

    delay(moveDelay);
  }
}

// =====================================================
// ACTIVE PUSH-UP PAIR + SUPPORT PAIR HOLD
// =====================================================
// active pair moves up/down
// support pair stays fixed in lowered pose
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

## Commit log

2026-03-14 Create one leg gait.ino
2026-03-22 Add files via upload
    printed
    [12servo - cover12servo-1.STL, 12servo - holder3-1.STL, leg left - RIGHT Lower Leg simpleMirror-2.STL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]
2026-06-11 Create Esp32_code
